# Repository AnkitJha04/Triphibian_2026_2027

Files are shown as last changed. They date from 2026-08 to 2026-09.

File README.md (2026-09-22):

# BE Capstone Project

## Project Title

RiftWalker: The Triphibious Bot

---

## Team Details

| Sr. No. | Name of Student | Roll No. | Branch | Email ID |
|---|---|---|---|---|
| 1 | Ankit Jha | 41 | Automation and Robotics  | 2023.ankitkumar.jha@ves.ac.in |
| 1 | Nidhi Kulkarni  | 15 | Automation and Robotics  | 2023.nidhi.kulkarni@ves.ac.in |
| 1 | Yadnyee Joshi | 10 | Automation and Robotics  | 2023.yadnyee.joshi@ves.ac.in  |
| 1 | Dnyanam Gala | 36 | Automation and Robotics  | 2023.dnyanam.gala@ves.ac.in |

---

## Guide Details

**Project Guide: Mrs. Sangeeta Prasanna Ram**  
**Department:** Automation and Robotics  
**Institute:** VESIT, Mumbai  

---

## Problem Statement

The objective of this project is to create an innovative, small unmanned robotic system that can function in air, land, and water domains through a unified propulsion and control mechanism and thus eliminates the requirement of using different systems such as UAV, UGV, and surface water vehicles in multi-environment missions.

Traditional unmanned systems are usually designed to work in one environment only. While the UAV offers high-speed flying abilities, it lacks endurance; the land robot offers efficiency but is limited by terrain; and the surface vehicle is incapable of crossing land barriers.

Recent studies have shown that integration of these two technologies is possible; however, triphibious robots are far fewer in number compared to dual-environment robots since integration leads to more weight and complexity in design and control, in addition to increased energy consumption.

---

## Abstract

Unmanned robotic systems are being increasingly employed for surveillance purposes, inspection tasks, emergency rescue operations and monitoring of the environment. But since most of these platforms are designed for one environment only, which could be air, land or water, missions in complex environments would either necessitate the use of multiple vehicles or halt the mission as the platform encounters the environment it cannot negotiate. It has been shown through studies on multimodal robots that multimodality is useful in increasing accessibility but it brings with it some difficulties in terms of weight, efficiency, mechanics and control.

The Riftwalker is a prototype of a triphibious robotic platform that aims to study movement in air, land and surface water using the same vehicle architecture. The platform uses four brushless motors as the source of propulsion in aerial environment while servo motors are used to orient the motors for different modes of operation. Passive wheels help the robot move on the ground while elements providing buoyancy help the robot operate in surface water environment.

The current design target has an approximately 2.2 kg maximum take-off mass, with calculated/design-stage performance targets of approximately 58 km/h aerial speed, 78 km/h peak ground speed and 10 km/h surface-water speed. These values will be treated as design targets until experimentally validated.

The expected outcome is a functional prototype demonstrating controlled movement and transition between three operating domains for applications including search and rescue, environmental surveying, inspection and remote reconnaissance.

Youtube video link :- https://youtu.be/WmMp18_r6lU

---

## Objectives

1. To study existing **multimodal and triphibious robotic platforms** and identify the challenges associated with integrating aerial, terrestrial and surface-water mobility into a single robotic system.

2. To develop a **3D CAD model** of the RiftWalker incorporating the structural frame, BLDC motor assemblies, servo-based tilting mechanism, wheels, buoyancy elements and electronics enclosure.

3. To design a **servo-based thrust vectoring mechanism** that changes the orientation of the BLDC propulsion units to enable different modes of locomotion using a unified propulsion system.

4. To perform **engineering calculations and feasibility analysis** including component-wise weight estimation, thrust-to-weight ratio, servo torque, battery and power requirements, land mobility, and water buoyancy.

5. To develop a custom **ESP32-S3 based flight controller PCB** integrating power management, motor and servo interfaces, USB-C programming, battery voltage monitoring and required sensor interfaces.

6. To integrate onboard sensors including the **MPU6050 IMU, magnetometer, barometer, ultrasonic sensor and water sensor** for orientation, altitude, obstacle and environmental-state monitoring.

7. To validate the proposed mechanical and electronic design through **simulation, PCB ERC/DRC verification and prototype testing**, ensuring that the system meets the defined design requirements.

8. To fabricate and integrate the mechanical, electronic and control subsystems and evaluate the **air, land and surface-water operating modes** of the RiftWalker prototype.

9. To document the complete design process, calculations, implementation, testing and results, and identify **future improvements and applications** of the proposed multi-terrain robotic platform.

---

## Scope of the Project

This project will cover the following key areas:

1) **3D mechanical design** and development of the servo-based thrust vectoring mechanism.
2) Selection and integration of **BLDC motors, ESCs, servos, wheels and buoyancy elements**.
3) Design of a custom **ESP32-S3 based flight controller PCB** with sensor, motor and servo interfaces.
4) Integration of sensors including **MPU6050, magnetometer, barometer, ultrasonic and water sensors**.
5) **Engineering calculations and simulation** for weight, thrust, torque, power and buoyancy.
6) Prototype fabrication, hardware integration and **testing of air, land and water operation**.
7) Performance evaluation and documentation of the developed system.

---

## Existing System

Existing unmanned robotic systems are generally designed for operation in a specific environment. They can broadly be classified as follows:

| Platform | Strength | Main Limitation |
|--- |--- |--- |
| UAV | Fast aerial movement and access to difficult locations | High energy consumption and limited endurance |
| UGV | Efficient and stable terrestrial operation | Restricted by water, steep terrain and other obstacles |
| USV | Efficient operation on surface water | Limited terrestrial mobility |
| Dual-Mode Robot | Capable of operating in two environments | Cannot independently access the third environment |
| Triphibious Robot | Potential to operate in air, land and water | Higher mass, mechanical complexity and control requirements |

Research has demonstrated the feasibility of combining multiple modes of locomotion within a single robotic platform. Existing triphibious and multimodal systems have explored approaches such as shared propulsion systems, tilting or morphing mechanisms and integrated mobility structures.

However, combining three different modes of locomotion introduces several engineering challenges, particularly in terms of **weight, energy efficiency, mechanical complexity, controllability and endurance**.

# Limitations of Existing Systems

1. **Multiple System Requirement:** Using separate UAV, UGV and waterborne platforms increases equipment, transportation and operational complexity.

2. **Limited Endurance:** Aerial systems require continuous thrust to remain airborne, resulting in significant power consumption.

3. **Terrain Limitations:** Ground robots may be restricted by water or difficult terrain, while waterborne platforms cannot easily overcome land-based obstacles.

4. **Increased Mechanical Complexity:** Combining separate propulsion and mobility mechanisms for different environments can increase the overall weight, power requirements and mechanical complexity of the system.

These limitations motivate the development of **RiftWalker**, which investigates the feasibility of combining aerial, terrestrial and surface-water mobility within a single robotic platform while sharing major propulsion, power and control components.

---

## Proposed System

RiftWalker proposes one reconfigurable vehicle rather than three independent vehicles.

Main Idea
The same central platform carries the battery, controller, communication system, sensors and propulsion hardware through all operating modes. Components are reused wherever practical rather than adding an independent propulsion system for every environment.

Operating Principle :
Air Mode
Four A2212-class 1400 KV BLDC motors with 9050 propellers operate in a multicopter configuration. The present design calculations indicate approximately 4.72 kg combined maximum static thrust against a 2.20 kg MTOW, corresponding to a calculated thrust-to-weight ratio of approximately 2.15:1.

Land Mode
The vehicle lands onto its wheel system. Servo-controlled propulsion orientation redirects available thrust to generate terrestrial motion rather than requiring a completely separate high-power traction architecture.

Water Mode
Buoyant wheel/body elements keep the electronics and major structure above the waterline while redirected propulsion produces forward motion across the water surface.

Control System : 
An ESP32-S3-class controller is currently proposed for prototype-level control, handling functions such as:
1) Stabilization/PID control,
2) IMU and navigation sensor processing,
3) Propulsion commands,
4) Servo actuation,
5) Mode management,
6) Telemetry,
7) Waypoint navigation.

Expected Benefits :

The expected benefit is mobility flexibility rather than superior performance in every individual domain.

A purpose-built UAV will likely fly more efficiently, a dedicated UGV can achieve better terrestrial endurance, and a purpose-built USV will generally perform better on water. RiftWalker instead investigates whether somewhat reduced domain-specific efficiency can be accepted in exchange for one platform being able to continue a mission when the terrain changes.
That is a much stronger and more realistic technical proposition.

---

## System Architecture

                    ┌─────────────────────┐
                    │   HUMAN OPERATOR    │
                    │ Ground Control / UI │
                    └──────────┬──────────┘
                               │
                     Telemetry / Commands
                               │
                               ▼
                  ┌────────────────────────┐
                  │ ONBOARD CONTROL SYSTEM │
                  │      ESP32-S3          │
                  │                        │
                  │ • Mission Logic        │
                  │ • PID / Stabilization  │
                  │ • Sensor Fusion        │
                  │ • Mode Management      │
                  │ • Navigation           │
                  └───────┬────────┬───────┘
                          │        │
                 ┌────────┘        └───────────┐
                 ▼                             ▼
        ┌─────────────────┐          ┌─────────────────┐
        │ SENSOR SYSTEM   │          │ ACTUATION       │
        │                 │          │ SYSTEM          │
        │ IMU             │          │                 │
        │ GNSS / NavIC    │          │ 4 × ESC         │
        │ Altitude        │          │ 4 × BLDC        │
        │ Camera*         │          │ Vector Servos   │
        └─────────────────┘          └────────┬────────┘
                                             │
                         ┌───────────────────┼──────────────────┐
                         ▼                   ▼                  ▼
                    AIR MODE            LAND MODE          WATER MODE
                    Multirotor          Wheels +           Buoyancy +
                    Flight              Vector Thrust      Vector Thrust
                         │                   │                  │
                         └───────────────────┼──────────────────┘
                                             ▼
                                  MULTI-DOMAIN MOBILITY

                     ┌─────────────────────────────┐
                     │       POWER SYSTEM          │
                     │  4S 6200 mAh LiPo Battery   │
                     │  Power Distribution / BEC   │
                     └─────────────────────────────┘

## System Architecture

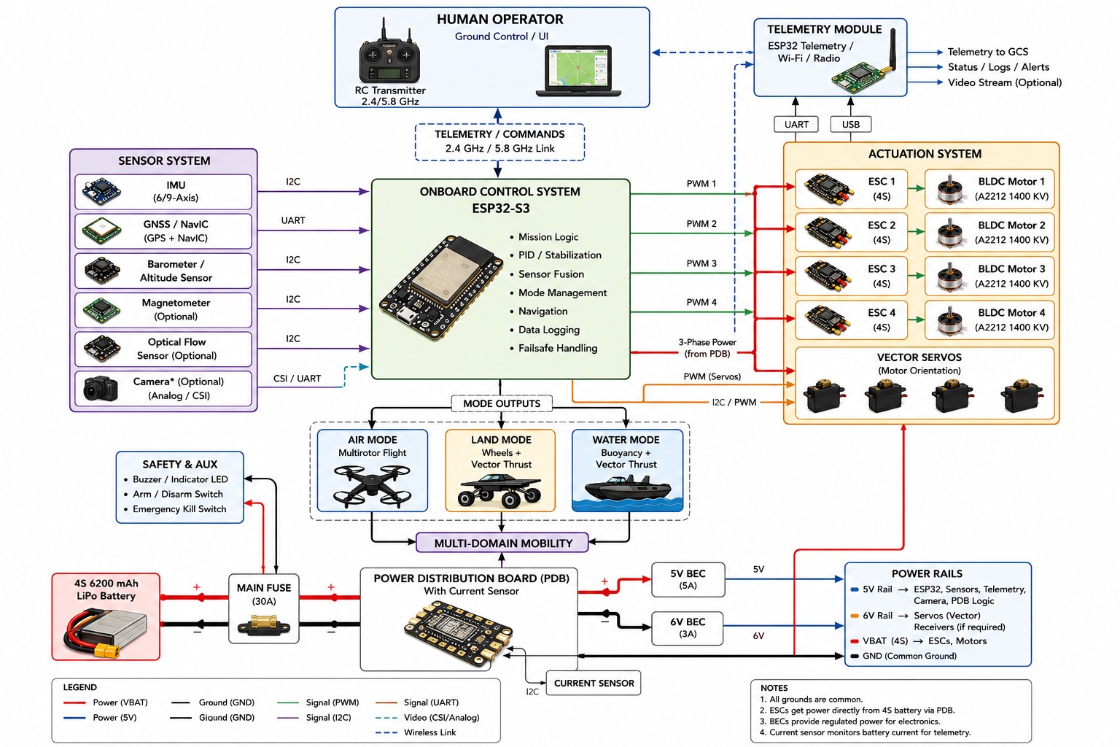
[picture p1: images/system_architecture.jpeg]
RiftWalker System Architecture


The RiftWalker system architecture is divided into four main sections:

Control System: The onboard controller acts as the brain of the robot. It processes sensor data, manages stabilization and navigation, controls propulsion, and switches between air, land, and water modes.
Sensor & Navigation System: Sensors such as the IMU and GNSS/NavIC provide information about orientation, position, motion, and vehicle state. Additional cameras or perception sensors can be integrated for autonomous navigation.
Propulsion & Actuation System: Four BLDC motors with ESCs generate thrust. Servo mechanisms change the direction of the propulsion system depending on the operating mode—vertical thrust for flight and redirected thrust for movement on land or water.
Power & Communication System: A 4S 6200 mAh LiPo battery supplies the motors, servos, controller, and sensors. A wireless telemetry link allows the ground operator to send commands and receive vehicle data.

Overall, the architecture is designed around sharing the same propulsion, power, sensing, and control hardware across all three environments, reducing the need for separate systems for each mode.

---

## Hardware Requirements

| Sr. No. | Component | Specification | Quantity | Purpose |
| --- | --- | --- | --- | --- |
| 1 | BLDC Motor | A2212, 1400 KV | 4 | Common propulsion for air, land and water |
| 2 | Propeller | 9050, matched to motor | 4 | Generates aerodynamic thrust |
| 3 | ESC | 4S-compatible, appropriately rated | 4 | Controls BLDC motor speed |
| 4 | LiPo Battery | 4S, 6200 mAh | 1 | Main onboard power source |
| 5 | Microcontroller | ESP32-S3 | 1 | Main control, sensor processing and telemetry |
| 6 | IMU | 6/9-axis accelerometer + gyroscope | 1 | Orientation, motion and stabilization |
| 7 | Sensor (Water/Distance) | Relevent to the use case | 1 | Outdoor positioning and navigation |
| 8 | Servo Motors | High-torque, metal-gear | 4 | Changes propulsion orientation between modes |
| 9 | Wheels | Lightweight passive/free-rolling | 4 | Supports terrestrial locomotion |
| 10 | Buoyancy System | Lightweight waterproof floats/body | 1 set | Provides stability and flotation on water |
| 11 | Power Distribution/BEC  | 4S compatible | 1 | Distributes and regulates electrical power |
| 12 | Telemetry System | Wireless bidirectional link | 1 | Operator commands and vehicle telemetry |
| 13 | Camera | Lightweight onboard camera | 1 | Visual feedback/perception |
| 14 | Frame & Mounting System | Lightweight rigid structure | 1 | Supports all mechanical and electronic components |
| 15 | Flight Controller | Custom | 1 | For functioning of everything perfectly |
---

## Software Requirements

| Sr. No. | Software / Tool | Version | Purpose |
| --- | --- | --- | --- |
| 1 | Arduino IDE / PlatformIO | Current stable | ESP32-S3 firmware development |
| 2 | Embedded C/C++ | Current toolchain | Low-level control and sensor interfacing |
| 3 | Python | 3.x | Data analysis, testing and algorithm prototyping |
| 4 | MATLAB / Simulink | Available release | Modelling, PID tuning and system analysis |
| 5 | Inventor | Available release | Mechanical CAD and assembly design |
| 6 | KiCad | Current stable | PCB and electronic system design |
| 7 | Git / GitHub | Current stable | Version control and project documentation |
| 8 | SimScale / OpenFOAM | Current stable | Computational Fluid Dynamics (CFD) simulation |
| 9 | Wokwi | Current stable | Headless hardware testing prior to flashing. |

---

## Technologies Used

1. **Embedded Systems:** ESP32-S3 and Embedded C/C++ for vehicle control and sensor interfacing.
2. **Sensor Integration & Control:** Integration of IMU, magnetometer, barometer, ultrasonic and water sensors for vehicle-state monitoring and control.
3. **PID Control:** PID-based stabilization and control of the propulsion system and vehicle motion.
4. **PCB Design (EDA):** KiCad for schematic design, component selection, PCB layout, routing and ERC/DRC verification.
5. **CAD & Mechanical Design:** Autodesk Inventor for 3D modelling, assembly design and development of the mechanical structure.
6. **Thrust Vectoring:** Servo-controlled motor orientation for redirecting propulsion across different operating modes.
7. **Multirotor Propulsion:** BLDC motors, ESCs and propellers for aerial propulsion.
8. **Power Management:** Separate logic and servo power domains with battery voltage monitoring and regulated power supplies.
9. **Wireless Communication:** Wireless communication for vehicle control and telemetry.
10. **Simulation & Engineering Analysis:** Mechanical and system-level analysis along with calculations for weight, thrust-to-weight ratio, servo torque, power requirements and buoyancy.

---

## Methodology

1. **Literature Survey:** Study existing multimodal and triphibious robotic platforms to understand their propulsion mechanisms, mobility approaches, control strategies and limitations.
2. **Problem Identification and Requirement Analysis:** Identify the major challenges involved in combining air, land and water mobility and establish the mechanical, electrical and performance requirements of RiftWalker.
3. **Concept Development:** Evaluate different multi-terrain mechanisms and finalize the use of a unified BLDC propulsion system with a **servo-based thrust vectoring mechanism**.
4. **Mechanical Design:** Develop the **3D CAD model in Fusion 360**, including the structural frame, motor mounts, servo tilting mechanism, wheels, buoyancy elements and electronics enclosure.
5. **Engineering Analysis:** Perform weight estimation, thrust-to-weight ratio, servo torque, battery and power, land mobility and buoyancy calculations to evaluate the feasibility of the proposed design.
6. **Simulation and Design Validation:** Validate the proposed mechanical concept and operating principle through simulation and analysis, and modify the design based on the obtained results.
7. **Electronic System Development:** Design the custom **ESP32-S3 based flight controller PCB** in KiCad, including power management, motor and servo interfaces, sensor interfaces, USB-C programming and battery monitoring.
8. **PCB Verification and Hardware Integration:** Perform schematic checks, ERC/DRC verification and PCB routing, followed by fabrication and integration of the controller with the motors, servos, sensors and power system.
9. **Firmware and Control Development:** Develop the ESP32-S3 firmware for sensor processing, stabilization, motor and servo control, communication and operating-mode management.
10. **Testing and Validation:** Test the integrated prototype in air, land and surface-water modes and evaluate parameters such as stability, mobility, thrust-vectoring response, power consumption and transition behaviour.
11. **Performance Analysis and Documentation:** Compare experimental results with calculated design values, identify limitations and improvements, and document the complete design, implementation and testing process.

---

## Project Timeline

| Week / Month | Task Planned | Status |
|---|---|---|
| **Week 1** | Problem Finalization & Project Planning | Completed |
| **Week 2** | Literature Survey & Research Paper Review | Completed |
| **Week 3** | Requirement Analysis & Component Selection | Completed |
| **Week 4** | Engineering Calculations | Completed |
| **Week 5** | Mechanical Design & 3D CAD Modelling | Completed |
| **Week 6** | Simulation & Design Validation | Completed |
| **Week 7** | Flight Controller PCB Design & Schematic Development | Completed |
| **Week 8** | PCB Routing, ERC/DRC Verification & Hardware Procurement | Completed |
| **Week 9** | PCB ic finalization & Component Weight testing | Completed |
| **Week 10**  | PCB Fabrication & Assembly | In Progress |
| **Week 11**  | Hardware Integration & Sensor Interfacing | In Progress |
| **Week 12**  | Firmware Development & System Testing | In Progress |
| **Week 13**  | Final Testing, Documentation & Project Demonstration | Pending |
| **Week 14**  | Research Paper Writing & Project Documentation | Pending |
| **Week 15**  | Final Presentation & Project Demonstration | Pending |

---

## Weekly Progress Updates

Students must update this section every week.
| Week  | Date | Work Completed | Next Week | Issues / Challenges | GitHub Commit |
|--- |--- |--- |--- |--- |--- |
| **1** | 22/06–28/06 | Problem finalization & planning | Literature survey | Concept feasibility | — |
| **2** | 29/06–05/07 | Literature survey & paper review | Requirement analysis | Mobility vs. weight | — |
| **3** | 06/07–12/07 | Requirements & components finalized | Engineering calculations | Weight, thrust & cost | — |
| **4** | 13/07–19/07 | Weight, thrust, torque & buoyancy calculations | Mechanical design | Maintaining low weight | — |
| **5** | 20/07–26/07 | 3D CAD model & mechanical design | Design validation & PCB | Mechanism integration | — |
| **6** | 27/07–02/08 | Design validation & simulation | PCB schematic | Mechanical-electronic integration | — |
| **7** | 03/08–09/08 | ESP32-S3 schematic & component selection | PCB routing & verification | GPIO & power management | — |
| **8** | 10/08–16/08 | PCB routing, ERC/DRC & documentation | PCB fabrication & procurement | Routing & component placement | — |
| **9** | 17/08–23/08 | Finalized and Completed PCB design verification| Working on software | Component availability | — |
| **10**| 24/08–30/08 | Made control center to control/code the drone  | PCB fabrication & procurement | Software needs and api development| — |

---

## Design Files

| File Type | File Name / Link | Description |
|-- |--- |--- |
| **CAD Model** | [Autodesk Inventor CAD Files](hardware/CAD/) | 3D mechanical model and assembly of RiftWalker |
| **Circuit Diagram** | [Circuit Diagram ](images/circuit_diagram-2.jpg) | Custom ESP32-S3 flight-controller schematic |
| **PCB Design** | [KiCad PCB Files](hardware/PCB/) | Custom flight-controller PCB design and routing |
| **ERC / DRC Reports** | [PCB Verification Files](hardware/PCB/) | Electrical and design rule verification reports |
| **Flowchart** | [System Flowchart](images/flowchart.jpeg) | Proposed operating sequence and control flow |
| **Simulation File** | [Wokwi Simulation Files](software/simulation/) | ESP32-based simulation files for preliminary testing | 

---

## Circuit Diagram

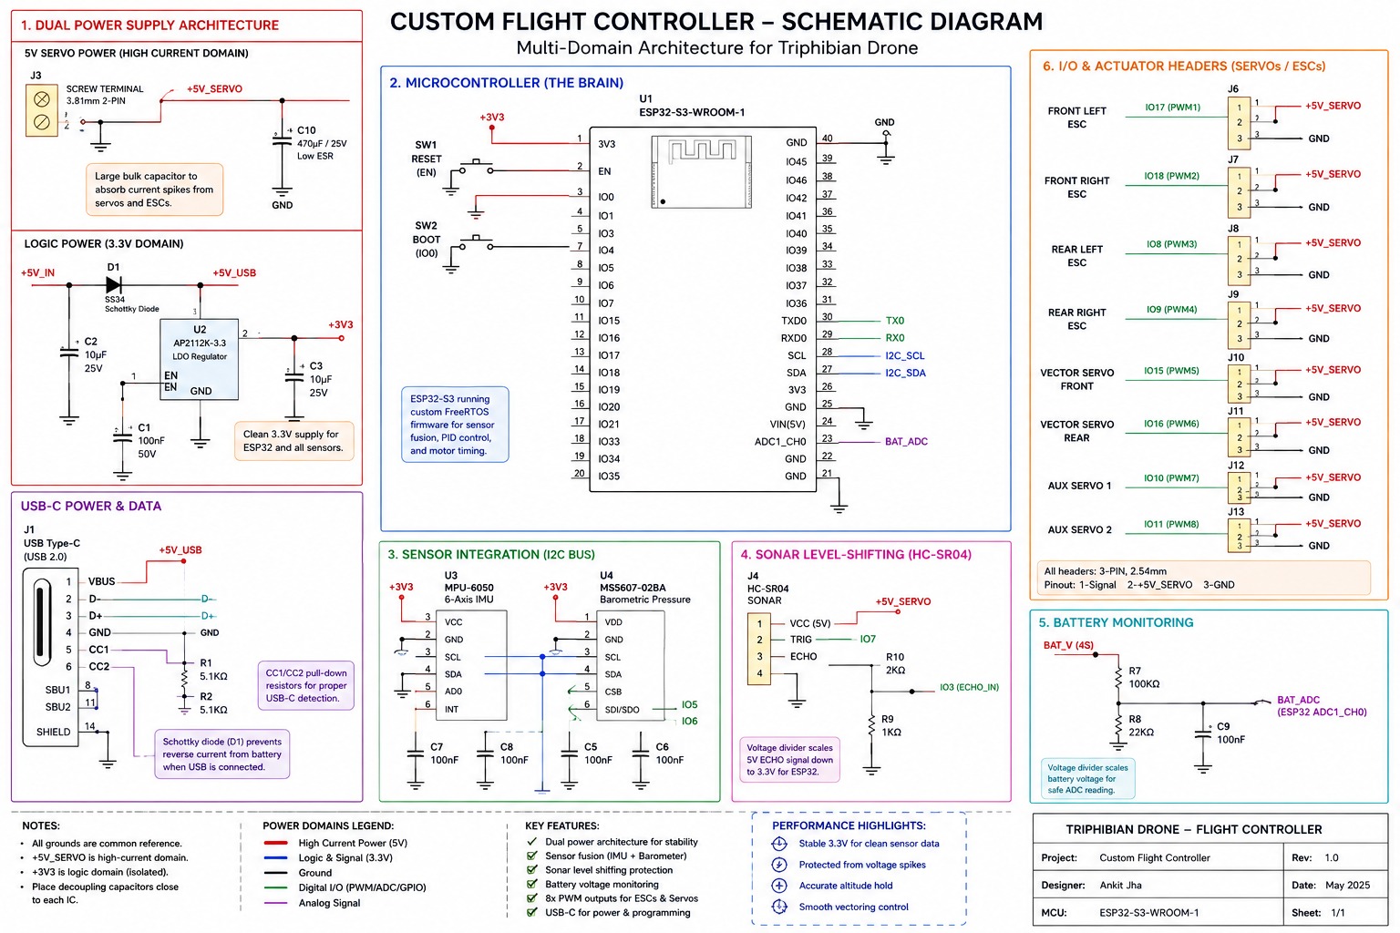
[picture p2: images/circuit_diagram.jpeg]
RiftWalker Circuit Diagram


---

## Flowchart / Algorithm

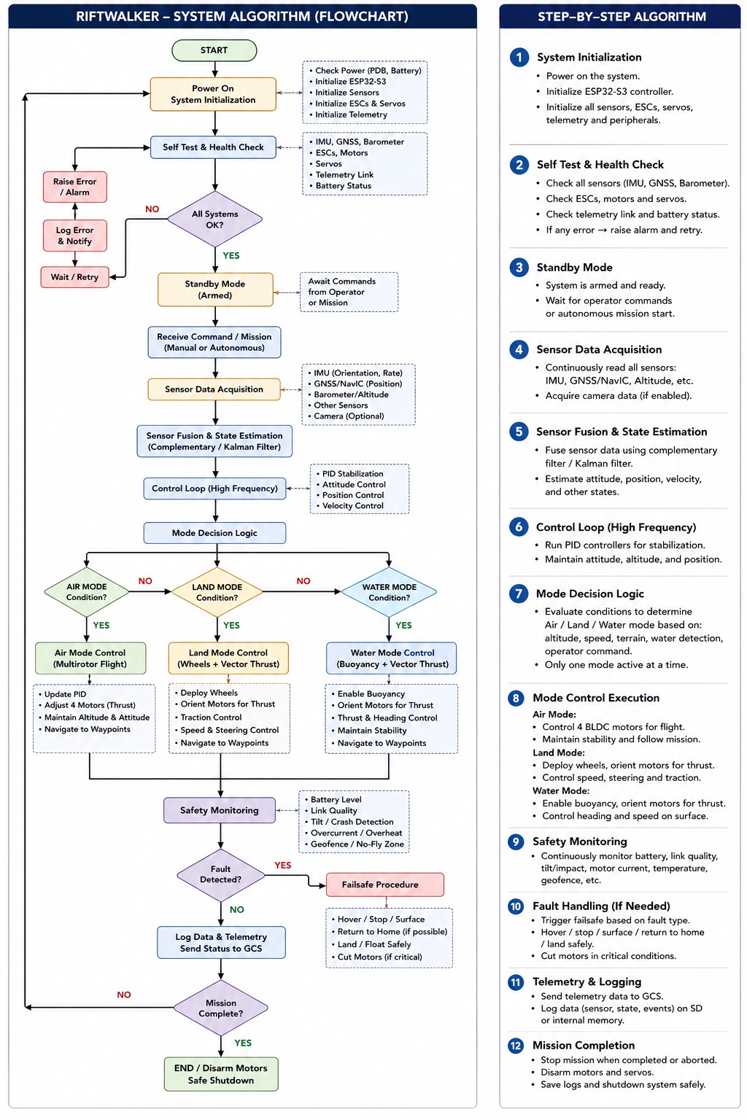
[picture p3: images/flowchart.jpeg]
RiftWalker Flowchart


### Algorithm

1. System Initialization – Power up the ESP32-S3 and initialize the IMU, GNSS/NavIC, altitude sensor, ESCs, servos and communication modules.
2. Self-Test & Health Check – Verify sensor communication, battery voltage, telemetry link and actuator status. Prevent arming if a critical fault is detected.
3. Standby / Arm – Keep propulsion disabled until a valid arm command and mission/operator command are received.
4. Sensor Acquisition – Continuously collect orientation, acceleration, altitude, position and other available sensor measurements.
5. Sensor Fusion & State Estimation – Combine measurements to estimate the robot's attitude, position, velocity and motion state.
6. Control Loop – Run the feedback controllers at high frequency to calculate the required thrust, attitude and motion corrections.
7. Mode Decision – Determine whether Air, Land or Water mode is requested/appropriate. For the prototype, operator-confirmed switching is safer than claiming fully autonomous terrain classification.
8. Execute Selected Mode – In Air Mode, operate as a multirotor; in Land Mode, redirect thrust and use the wheels; in Water Mode, maintain flotation and use vectored thrust for surface movement.
9. Navigation – Follow manual commands or mission waypoints while continuously updating the required heading, speed and position.
10. Safety Monitoring – Continuously check battery level, communication link, attitude, actuator/current limits and other available health information.
11. Failsafe Handling – If a critical fault occurs, execute the safest response available for the current mode, such as controlled landing, stopping propulsion, remaining afloat, or returning to a safe location where technically feasible.
12. Telemetry & Logging – Transmit vehicle status to the ground station and record important sensor, control and fault information.
13. Mission Check – If the mission is incomplete, return to the sensing/control loop. If complete, move to shutdown.
14. Safe Shutdown – Stop the mission, disarm propulsion and place actuators in their safe state.

---

## Implementation Details

The implementation of the RiftWalker project is divided into tightly integrated hardware and software phases, completely bypassing off-the-shelf drone kits in favor of a custom-engineered multi-domain architecture.

Hardware Implementation
Mechanical Frame & Buoyancy: The chassis utilizes custom Z-shaped carbon-fiber arms to elevate the propeller arcs, preventing aerodynamic thrust-blockage. Closed-cell XPS foam wheels are underslung on the chassis, providing mechanical ground clearance for land operations and acting as highly buoyant pontoons to keep the waterline below the main electronics bay during marine operations.

Actuation & Propulsion: The drive system relies on four BLDC motors mounted on rotating vectoring hubs. These hubs are actuated by high-torque DS3218 digital servos capable of sweeping the entire propulsion system 90 degrees forward for surface travel.

Custom Electronics (PCB): A custom-designed ESP32-S3 flight controller serves as the system's brain.

Power Distribution: The board features an isolated dual-power architecture. A high-current 5V rail (with a large bulk capacitor) drives the vectoring servos, while a dedicated AP2112K LDO regulator provides clean 3.3V power to the logic circuits, preventing brownouts.

Sensors: An MPU-6050 IMU and MS5607 barometer are mounted on the bottom layer of the PCB to shield them from thermal output and RF noise. An HC-SR04 ultrasonic sensor is integrated using a hardware voltage divider to safely step down the 5V echo pulse to the 3.3V logic level.

Software Implementation
Firmware Architecture: To handle the shape-shifting mechanics, the firmware was written entirely from scratch using C++ and FreeRTOS, bypassing the limitations of standard multirotor software.

Dual-Core Processing: The ESP32-S3’s dual-core capabilities are fully leveraged to ensure real-time stability:

Core 0 (Sensor Fusion): Dedicated exclusively to polling the IMU, barometer, and ultrasonic sensors. It calculates altitude and pressure to autonomously detect the operating domain (Air, Land, or Water).

Core 1 (Motor & PID Control): Strictly isolated to handle the high-speed PID stabilization loops and PWM timing for the ESCs and servos.

Concurrency & Safety: Hardware mutex locks are implemented to allow the two cores to share telemetry data safely. This guarantees that environmental sensor reads never delay the critical motor control loops, enabling instantaneous thrust-vectoring when transitioning between terrains.

## Code Structure

```text
BE-Capstone-Project/
│
├── README.md
│
├── docs/
│   └──  literature_survey.md
│
├── hardware/
│   ├── hardware.md
│   ├── pcb_design/
|       ├── DRC.rpt
|       ├── ERC.rpt
|       ├── Flight Controller.kicad_pcb
|       ├── Flight Controller.kicad_prl
|       ├── Flight Controller.kicad_pro
|       ├── Flight Controller.kicad_sch
|       ├── PCB Dimensions.png
|       ├── IC bom.xlsx
|       ├── README.md
|       └── fp-info-cache
│   ├── Tests/
|       ├── MotorAllSync.in
│   └── cad_model
|       ├── BLDC Holder.ipt
|       ├── BLDC Holder.stl
|       ├── Bearing.ipt
|       ├── Bearing.stl
|       ├── Body.ipt
|       ├── Body.stl
|       ├── Connecting Rod.ipt
|       ├── Connecting Rod.stl
|       ├── Final Body.iam
|       ├── Holder Cover.ipt
|       ├── Holder Cover.stl
|       ├── Motor.ipt
|       ├── Propeller.ipt
|       ├── README.md
|       ├── Servo.ipt
|       ├── Pcb Spacer.stl
|       ├── TEST ASSEMBLY 1.stl
|       ├── Top Cover.ipt
|       ├── Top Cover.stl
|       ├── Tyres.stl
|       └── Tyres.ipt
│
├── software/
│   ├── software.md
│   └── simulation/
|       ├── README.md
|       ├── diagram.json
|       ├── libraries.txt
|       ├── sketch.ino
|       └── wokwi-project.txt
|   └── Command and Control center/
|       ├── README.md
|       ├── index.html
|       ├── Commands.md
|       └── Application/
|           ├── README.md
|           ├── index.html
|           ├── app.py
|           ├── requirements.txt
│
├── images/
|   ├── circuit_diagram-2.jpg
|   ├── circuit_diagram.jpeg
|   ├── flowchart.jpeg
|   ├── images.md
|   └── system_architecture.jpeg
│
└── references/
    └── paper.md
```

---

## How to Run the Project

### Step 1: Clone the Repository

```bash
git clone https://github.com/username/project-name.git
```

### Step 2: Install Dependencies

```bash
pip install -r requirements.txt
```

or mention specific software/library installation steps.

### Step 3: Upload / Run the Code

```bash
python main.py
```

or

```bash
arduino-cli upload -p COMx --fqbn board_name
```

### Step 4: Observe the Output

When powered, the RiftWalker initializes its IMU and establishes a secure ESP-NOW link with the ground station, displaying battery voltage and current vector angles. Upon command, the craft can spool its motors to take off vertically like a standard drone, demonstrating stable hover capabilities. When the operator engages "Surface Mode," the servos smoothly rotate the motor arms $90^\circ$ forward while adjusting thrust to prevent altitude loss. On the ground or water, the vehicle utilizes differential aero-thrust to steer and propel itself forward at high speeds, gliding on its XPS wheels with a drastically reduced current draw compared to hovering.

---

## Testing and Results

| Test No. | Test Description | Expected Result | Actual Result | Status |
| --- | --- | --- | --- | --- |
| 1 | | | | Pass / Fail |
| 2 | | | | Pass / Fail |
| 3 | | | | Pass / Fail |

---

## Result Images / Videos

Add images or videos of the working prototype.

```markdown
![Prototype](images/prototype_photo.jpg)
```

Video Link:

```markdown
[Project Demo Video](https://drive.google.com/your-video-link)
```

---

## Applications

1. Post-Disaster Search & Rescue (SAR): Navigating through flooded urban environments, blocked roads, and debris dams where neither standard boats nor ground rovers can pass.
2. Hazardous Environmental Monitoring: Surveying toxic lakes, unstable wetlands, or swamp ecosystems without the risk of underwater propellers getting tangled in aquatic vegetation.
3. Tactical Reconnaissance & Border Patrol: Serving as a covert, multi-terrain sentinel capable of flying to a location rapidly and transitioning to a low-power, silent ground/water crawl for long-term observation.
4. Amphibious Ship-to-Shore Scouting: Launching from a naval vessel, flying to the coastline, and seamlessly driving onto the beach to conduct physical surveys.
ETC.

---

## Advantages

1. Elimination of Drivetrain Bloat: Achieves an exceptional 2.15:1 thrust-to-weight ratio by using a single set of aero-propellers for all terrains, eliminating the dead-weight of separate wheel motors and heavy gearboxes.
2. Exponential Endurance Gains: By dropping to the ground or water and operating as an aero-propelled rover, mission endurance is extended from a maximum of ~9.5 minutes in the air up to ~54.5 minutes on the surface.
3. Passive Buoyancy & Suspension: The lightweight XPS foam wheels serve a dual purpose, acting as excellent shock absorbers for rough terrain and fail-safe, unsinkable flotation hulls for water traversal.
4. Cost-Effective & Scalable: By eliminating redundant drive hardware and integrating a custom ESP32-based flight controller, the unit cost is drastically reduced compared to commercial military-grade amphibious systems.

---

## Limitations

1. Transition Vulnerability: The physical transition phase takes  seconds, during which the craft is highly susceptible to sudden crosswinds or aerodynamic stalling if not perfectly timed.
2. Ground Clearance Ceilings: Terrestrial obstacle clearance is strictly limited by the radius of the XPS wheels; the vehicle cannot drive over boulders or deep trenches without reverting to flight mode.
3. Acoustic Signature: Using aero-propulsion to drive on land generates significantly more noise (propeller wash) than a traditional electric wheeled rover, reducing its stealth capabilities in close-proximity scenarios.
4. Thermal Constraints: When planing on water at high throttle for extended periods, the enclosed central electronics box lacks active airflow cooling, potentially leading to thermal throttling of the ESCs.
   
---

## Future Scope

1. Autonomous AI Integration: Upgrading the processing core to incorporate a lightweight AI vision module (e.g., using the ESP32-S3's vector instructions or an external neural accelerator) for autonomous optical obstacle avoidance.
2. Triple-Redundant Aerospace Sensing: Developing a "V2" PCB that utilizes triple-redundant IMUs and Barometers connected via an SPI bus to create a fault-tolerant voting architecture for military-grade reliability.
3. BVLOS Telemetry Upgrade: Replacing the 2.4GHz ESP-NOW link with a secure, AES-encrypted Long Range (LoRa) 915MHz telemetry module for Beyond Visual Line of Sight (BVLOS) operations.
4. Aquatic Self-Righting Mechanism: Engineering an automated algorithmic response or physical mass-shifting mechanism to ensure the craft can self-right and recover if flipped upside down by heavy waves in water mode.
   
---

## Research Paper / Publication

| Item | Details |
| --- | --- |
| Paper Title | |
| Conference / Journal Name | |
| Paper Status | Not Started / Drafting / Submitted / Accepted / Published |
| Submission Date | |
| Paper Link | |

---

## References

[1] G. Zhong, J. Cao, X. Chai, and Y. Bai, "Design and Performance Analysis of a Triphibious Robot with Tilting-Rotor Structure," *IEEE Access*, vol. 9, pp. 10871–10879, 2021, doi: 10.1109/ACCESS.2021.3050182.

[2] X. Li, M. Lai, M. Zhang, J. Lin, T. Lai, J. Zhi, C. Xu, F. Gao, Y. Cao, "TriphiBot: A Triphibious Robot Combining FOC-based Propulsion with Eccentric Design," arXiv preprint arXiv:2602.01385, 2026.

[3] M. Xia, B. Wang, and Z. Luo, "Design and Experiment of a Multimodal Aerial Aquatic Vehicle with Morphing Wing and Tilting Rotors," *Advances in Mechanical Engineering*, vol. 17, 2025, doi: 10.1177/16878132251319142.

[4] S. L. Pradeep Kumar, B. Deeban, D. Santhosh Kumar, and M. Sasi Kumar, "Design and Fabrication of a Multi-Terrain Triphibian Quadcopter for Airborne, Terrestrial, and Aquatic Mobility," *Discover Mechanical Engineering*, vol. 5, art. no. 20, 2026, doi: 10.1007/s44245-025-00167-7.

[5] Z. Zheng, Q. Cai, J. Wang, X. Xu, M. Cao, H. Yu, J. Li, J. Meng, and G. Lu, "CapsuleBot: A Novel Hybrid Aerial-Ground Bi-Copter Robot With Two Actuated-Wheel-Rotors," *IEEE Robotics and Automation Letters*, vol. 10, no. 1, pp. 120–127, 2025, doi: 10.1109/LRA.2024.3504232.

---

## Repository Update Guidelines

Each student team must update the GitHub repository regularly.

Minimum expected updates:

* Update README every week.
* Push code changes regularly.
* Upload circuit diagrams, CAD files, PCB files, reports and presentations.
* Add weekly progress in the progress table.
* Maintain proper folder structure.
* Do not upload unnecessary temporary files.
* Each major update should have a meaningful commit message.

Example commit messages:

```text
Added problem statement and objectives
Updated system architecture diagram
Added sensor interfacing code
Updated weekly progress for Week 3
Added testing results and prototype images
```

---

## Declaration

We declare that this project work is carried out by our team as part of the BE Capstone Project. The work will be regularly updated on GitHub and all references used will be properly cited.

---

## License

This project is for academic use only.

Optional:

```text
MIT License / Creative Commons / Institute Use Only
```

```
```

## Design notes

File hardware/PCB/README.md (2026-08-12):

# RiftWalker PCB Design

This folder contains the KiCad schematic, PCB layout and verification files for the custom ESP32-S3 flight controller.

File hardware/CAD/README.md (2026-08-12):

# RiftWalker CAD Files

This folder contains the Autodesk Inventor 3D model and mechanical design files of RiftWalker.

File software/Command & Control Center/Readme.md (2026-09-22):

# RIFTWALKER / TRIPHIBIOUS COMMAND DECK — FINAL

Canonical interface file: **`Index.html`**

Desktop app: **`Application/app.py`** (loads that HTML). See the root `README.md` for run commands.

## What this build is based on
This build was rebuilt from the supplied project material rather than from the earlier generic dashboard alone:

- `Project Overview.md` — primary project architecture and operating principle.
- `Algorithm.png` — system initialization, health check, standby, sensor acquisition, fusion, control loop, mode decision, safety monitoring, failsafe and mission-completion flow.
- `Circuit Diagram Schematic Accurate.png` — custom flight-controller architecture and component/power/signal relationships.
- `Circuit Diagram.png` and `System Architecture.png` — system-level arrangement and multi-domain actuation/sensing relationships.
- `Major Project Simulation.zip` — Wokwi/ESP32 prototype firmware and wiring. This is treated as a prototype reference, not silently substituted for the final PCB.
- `Related Defence Projects.pdf` — supplied application/use-case material.
- Previous RiftWalker HTML files — used for visual/tactical presentation language only, not as the technical authority.

## Important source reconciliation
The project overview describes the final propulsion architecture as four A2212 BLDC motors, four ESCs and four 1045 propellers with four servo-driven motor pivots. The supplied Wokwi simulation is a bench prototype using an ESP32 DevKit, MPU6050, BMP180, SSD1306, HC-SR04, four A4988 drivers/stepper motors and four servos. The dashboard deliberately keeps these two layers separate so a prototype component is not presented as a final hardware component.

## Included functionality

### 1. Digital twin
- Four propulsion pods and four vector pivots.
- A2212 + 1045 propulsion representation.
- Four foam wheels for land contact and water buoyancy.
- Air / Land / Water state-dependent animation.
- Animated propeller motion tied to throttle.
- Vector angle moves at 120 degrees/second in the local model, matching the documented prototype design intent.
- Camera presets and mouse orbit/zoom on the flight view.

### 2. Telemetry
Local simulation is always functional and deterministic. It reports:
- mode
- throttle
- speed
- altitude/distance
- pressure
- battery
- roll
- pitch
- current
- power
- individual vector-servo state (front/rear mirror values follow the uploaded prototype's `180-angle` / `angle` mapping)

The UI does **not** call local simulation telemetry “hardware telemetry”.

Environment pressure scales thrust, speed, and current once per simulation step. It does not compound every animation frame.

### 3. Real ESP32 link
The Ground Control tab uses this explicit contract:

- `GET /health`
- `GET /telemetry`
- `POST /command` with JSON

Example telemetry response:

```json
{
  "ok": true,
  "mode": "air",
  "throttle": 42,
  "vector": 90,
  "altitude": 1.25,
  "pressure": 998.4,
  "speed": 18.2,
  "roll": -1.1,
  "pitch": 2.4,
  "battery": 91,
  "current": 18.6,
  "power": 275
}
```

Example command response:

```json
{
  "ok": true,
  "applied": true,
  "command": "SET_THROTTLE"
}
```

The interface only displays `ACK`/`APPLIED` after the device actually answers. Network failure is shown as `FAIL`.

### 4. Hardware / PCB
The interactive PCB map follows the supplied custom schematic's logical placement:
- ESP32-S3 central controller
- MPU6050 / magnetometer sensor area
- AP2112K 3.3 V regulation area
- ESC outputs
- vector-servo outputs
- propulsion/wheel blocks
- USB-C service
- battery ADC
- prototype sonar/water sensing

The exact supplied schematic is also available inside the Hardware tab.

### 5. Use cases
The mission library is custom to the supplied triphibious architecture:
- Flood Rescue / Access
- Coastal Survey
- Hazardous Area Inspection
- Industrial / Dam Inspection
- Disaster Recon
- Wetland / Environment

Each scenario has its own environment sequence, route, phase list and animation rather than a generic route reused for every case.

## Prototype pin map retained from the uploaded Wokwi code
The uploaded prototype uses:

| Function | GPIO |
|---|---:|
| FWD / BCK | 26 / 25 |
| LEFT / RIGHT | 17 / 15 |
| WATER | 16 |
| Throttle ADC | 34 |
| Ultrasonic | TRIG 5 / ECHO 35 |
| Vector servos | 18 / 19 / 23 / 4 |
| Step outputs | 27 / 14 / 13 / 12 |
| DIR | 32 / 33 |
| I2C SDA / SCL | 21 / 22 |

The firmware also uses FreeRTOS tasks for motor and sensor processing.

## Why the previous telemetry problem is not hidden
The uploaded Wokwi sketch does not implement a Wi-Fi HTTP telemetry server. Therefore a browser cannot truthfully fetch live hardware telemetry directly from that exact sketch. This dashboard therefore:

1. runs a complete local simulation without pretending it is hardware;
2. provides the hardware API adapter separately;
3. requires the ESP32 firmware to expose `/health`, `/telemetry` and `/command` before it will show real device ACK/data.

This is intentional: a green “ESP32 LIVE” indicator is never produced merely because the UI changed a local variable.

## Run
**Browser:** open `Index.html`.

**Desktop:** `python Application/app.py` after `python -m pip install -r Application/requirements.txt`.

No CDN or framework is required for the simulation interface.

For hardware mode, the client must reach the ESP32 IP and the firmware must implement the API contract above. CORS must be allowed when the page is not served from the ESP32 origin.

## Recommended hardware-side next step
Add the API adapter to the actual ESP32-S3 firmware. Do not retrofit the Wokwi stepper/A4988 test architecture into the final PCB merely to make the dashboard appear to work. The final project documentation identifies A2212/ESC/1045 propulsion and servo-based motor orientation; the Wokwi file is the prototype test bench.

## Safety
This interface is a visualization/control-deck prototype. It must not be used as a safety-certified flight controller. Real motor/servo testing should be performed with propellers removed or in an appropriate restrained test setup and with an independent physical emergency-disarm path.

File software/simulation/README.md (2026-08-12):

# RiftWalker Wokwi Simulation

This folder contains the Wokwi-based simulation files used for preliminary testing of the ESP32 control system, sensors, servo outputs and motor-control interfaces.

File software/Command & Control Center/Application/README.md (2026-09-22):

# Riftwalker Triphibious Command Deck (desktop)

Native Python window for the Command Deck. It hosts the exact same interface as `TRIPHIBIOUS_Command_Deck_FINAL_FIXED.html` (copied here as `index.html`).

## Requirements

- Windows 10/11
- Python 3.10 or newer
- Packages in `requirements.txt` (PySide6 + Qt WebEngine via PySide6-Addons)

## Install and run

```powershell
cd Application
python -m pip install -r requirements.txt
python app.py
```

From the project root:

```powershell
python -m pip install -r Application\requirements.txt
python Application\app.py
```

On Windows you can also double-click `run.bat` in this folder. If Python packages are missing, that script installs `requirements.txt` and starts the app.

If Qt WebEngine is missing:

```powershell
python -m pip install --upgrade PySide6 PySide6-Addons PySide6-Essentials
```

## What it loads

`app.py` serves and displays, in this order if present:

1. `../TRIPHIBIOUS_Command_Deck_FINAL_FIXED.html`
2. `TRIPHIBIOUS_Command_Deck_FINAL_FIXED.html` in this folder
3. `index.html` in this folder

`index.html` is kept identical to the canonical HTML so this folder remains runnable by itself.

## Features (same as the HTML deck)

- Dark Riftwalker command-deck UI
- SYSTEM, DIGITAL TWIN, HARDWARE / PCB, USE CASES, GROUND CONTROL, REFERENCE GALLERY
- Digital twin with chassis, battery bay, four motor pods, vector pivots, propellers, tyres, and foam floats
- Drag to orbit, wheel to zoom, ISO / TOP / FRONT / SIDE cameras
- Air / Land / Water modes; vector tilts propellers only
- Environment pressure and Ground Control UP / DOWN move the model inside the same canvas
- Throttle, vector, and environment pressure
- Local telemetry; ESP32 feed only after a real device ACK
- Local telemetry; ESP32 feed only after a real device ACK
- Scrollable reference gallery with the supplied project images

## Hardware adapter

Unchanged API:

- `GET /health`
- `GET /telemetry`
- `POST /command`

Default device URL in Ground Control: `http://192.168.4.1`

The desktop app remains fully usable in local simulation if no ESP32 is connected.

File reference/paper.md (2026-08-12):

# RiftWalker Academic Literature Foundation

**Overview:** This document outlines the primary academic literature that established the theoretical and mechanical foundation for the RiftWalker project. Each paper below played a specific, critical role in shaping our engineering decisions, from the unified propulsion architecture to the fluid-dynamic structural design.

---

### [1] Design and Performance Analysis of a Triphibious Robot with Tilting-Rotor Structure
* **Citation:** G. Zhong, J. Cao, X. Chai, and Y. Bai, "Design and Performance Analysis of a Triphibious Robot with Tilting-Rotor Structure," *IEEE Access*, vol. 9, pp. 10871–10879, 2021. 
* **DOI:** [10.1109/ACCESS.2021.3050182](https://doi.org)

#### How it influenced RiftWalker
This research validated tilt-rotor thrust vectoring across air, land, and water environments, directly inspiring our 90-degree servo-actuated motor tilt mechanism.
---

### [2] TriphiBot: A Triphibious Robot Combining FOC-based Propulsion with Eccentric Design
* **Citation:** X. Li, M. Lai, M. Zhang, J. Lin, T. Lai, J. Zhi, C. Xu, F. Gao, Y. Cao, "TriphiBot: A Triphibious Robot Combining FOC-based Propulsion with Eccentric Design," *arXiv preprint arXiv:2602.01385*, 2026.
* **Link:** [arXiv:2602.01385](https://arxiv.org)

#### How it influenced RiftWalker
This paper’s core thesis on unified propulsion architecture demonstrated unified cross-medium propulsion without extra actuators, confirming that reusing flight motors eliminates the parasitic mass of secondary drivetrains.
---

### [3] Design and Experiment of a Multimodal Aerial Aquatic Vehicle with Morphing Wing and Tilting Rotors
* **Citation:** M. Xia, B. Wang, and Z. Luo, "Design and Experiment of a Multimodal Aerial Aquatic Vehicle with Morphing Wing and Tilting Rotors," *Advances in Mechanical Engineering*, vol. 17, 2025.
* **DOI:** [10.1177/16878132251319142](https://doi.org)

#### How it influenced RiftWalker
This study evaluated structural and aerodynamic adaptations for cross-domain transitions, guiding our Z-shaped offset arm geometry to prevent propeller downwash from hitting the main chassis.

---

### [4] Design and Fabrication of a Multi-Terrain Triphibian Quadcopter for Airborne, Terrestrial, and Aquatic Mobility
* **Citation:** S. L. Pradeep Kumar, B. Deeban, D. Santhosh Kumar, and M. Sasi Kumar, "Design and Fabrication of a Multi-Terrain Triphibian Quadcopter for Airborne, Terrestrial, and Aquatic Mobility," *Discover Mechanical Engineering*, vol. 5, art. no. 20, 2026.
* **DOI:** [10.1007/s44245-025-00167-7](https://doi.org)

#### How it influenced RiftWalker
While other papers focused heavily on kinematics, this research provided a practical design and fabrication benchmark for multi-terrain quadcopters, shaping our modular chassis build and tactical real-world deployment cases.

---

### [5] CapsuleBot: A Novel Hybrid Aerial-Ground Bi-Copter Robot With Two Actuated-Wheel-Rotors
* **Citation:** Z. Zheng, Q. Cai, J. Wang, X. Xu, M. Cao, H. Yu, J. Li, J. Meng, and G. Lu, "CapsuleBot: A Novel Hybrid Aerial-Ground Bi-Copter Robot With Two Actuated-Wheel-Rotors," *IEEE Robotics and Automation Letters*, vol. 10, no. 1, pp. 120–127, 2025.
* **DOI:** [10.1109/LRA.2024.3504232](https://doi.org)

#### How it influenced RiftWalker
This paper demonstrated dual-use actuator sharing between aerial flight and ground rolling, inspiring our reliance on differential thrust and dual-purpose wheels over heavy steering racks.

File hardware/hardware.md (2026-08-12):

<div align="center">
  <h1 style="font-family: 'Helvetica Neue', Arial, sans-serif; font-weight: 300; letter-spacing: 3px; color: #1a202c; margin-bottom: 0;">
    HARDWARE ARCHITECTURE
  </h1>
  <p style="font-size: 1.3em; color: #3182ce; font-weight: bold; margin-top: 5px; letter-spacing: 1.5px;">
    RiftWalker: Unified Triphibious Robotics
  </p>
  <hr style="width: 120px; border: 2px solid #3182ce; border-radius: 2px; margin-top: 15px; margin-bottom: 35px;">
</div>

<blockquote>
  <strong>Welcome to the RiftWalker Hardware Repository.</strong> This document outlines the physical engineering and custom avionics required to build the RiftWalker platform. By completely abandoning off-the-shelf drone frames and standard flight controllers, this hardware is purpose-built to eliminate parasitic dead-weight and enable unrestricted multi-domain mobility across Air, Land, and Water.
</blockquote>

<br>

---

##  Repository Structure

```text
├── /CAD            # 3D models and structural files
    Required Cad Files
├── /PCB            # KiCad project files and Schematics
    Required PCB Files
```

<br>

---

## Mechanical Design (Frame & Actuation)

The physical chassis is explicitly engineered to solve two major triphibious challenges: aerodynamic blockage and terrain-locking.

*   **Z-Shaped Carbon-Fiber Arms:** The motor arms step upwards in a distinct Z-shape. This elevates the propeller arc, completely clearing the main chassis from the downward airflow, thereby preventing parasitic thrust-blockage.
*   **Dynamic Vectoring Hubs:** Instead of adding extra drivetrains, high-torque digital servos physically sweep the BLDC propulsion system **90 degrees forward**. This allows RiftWalker to steer using differential thrust on both the ground and water.
*   **Multi-Domain XPS Wheels:** The underslung wheels are constructed from closed-cell XPS foam. On land, they provide mechanical ground clearance; on water, they act as precisely calculated buoyant pontoons, forcing the waterline strictly below the electronics bay.

<br>

---

## Custom Avionics (ESP32-S3 PCB)

Off-the-shelf flight controllers are bloated and strictly designed for single-domain use. We engineered a custom **ESP32-S3-WROOM-1** PCB from scratch to gain total hardware access for our dual-core FreeRTOS architecture.

### Key PCB Design Decisions:

#### 1. Strict Power Isolation
*   **Logic (3.3V):** Powered by an AP2112K LDO regulator, providing clean, stable power to the ESP32 and $I^2C$ sensors.
*   **Actuators (5V):** Servo power is completely decoupled from the logic circuit. A large bulk polarized capacitor (`C10`) is placed on the 5V rail to absorb the massive current spikes caused by the vectoring servos, preventing mid-air brownouts.

#### 2. Sensor Thermal & RF Shielding
The **MPU-6050** (6-axis IMU) and **MS5607** (Barometer) are intentionally mounted on the **bottom layer** of the PCB. This physically isolates them from the ESP32’s thermal output and RF noise, ensuring perfectly clean environmental data.

#### 3. Antenna Keep-Out Zone
A strict copper keep-out zone is enforced around the ESP32 antenna to maximize telemetry and control range across all terrains.

#### 4. Safe Logic-Level Shifting
The HC-SR04 ultrasonic sensor outputs a 5V echo pulse. A precise $2\text{k}\Omega / 1\text{k}\Omega$ hardware voltage divider safely steps this down to 3.3V, protecting the microcontroller's GPIO pins.

<br>

---

## Bill of Materials (Core Components)

| Component | Description | Qty |
| :--- | :--- | :---: |
| **ESP32-S3-WROOM-1** | Dual-core MCU for custom FreeRTOS flight logic | 1 |
| **MPU-6050** | 6-Axis IMU (Pitch/Roll/Yaw stabilization) | 1 |
| **MS5607-02BA** | High-precision barometer for altitude detection | 1 |
| **HC-SR04** | Ultrasonic distance sensor | 1 |
| **BLDC Motors & ESCs** | Primary unified propulsion | 4 |
| **High-Torque Servos** | Actuates the 90-degree vectoring sweep | 4 |
| **AP2112K-3.3** | 3.3V Low-Dropout Voltage Regulator | 1 |

<br>

---
*For software implementation, firmware flashing instructions, and FreeRTOS details, please refer to `SOFTWARE.md`.*

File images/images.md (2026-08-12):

# RiftWalker Visual Repository

Welcome to the RiftWalker Visual Repository. This document serves as a visual index and explanation for the core engineering diagrams driving our platform. It breaks down the high-level mechatronic architecture, the custom electrical routing, and the dual-core software logic required for seamless triphibious operation.

---

## 1. System Architecture
*Reference: `system_architecture.jpeg`*

This diagram illustrates the top-down flow of commands and the physical unification of our hardware.

* **The Command Flow:** Human operator telemetry is received by the **ESP32-S3 Onboard Control System**. This central brain handles mission logic, PID stabilization, and sensor fusion.
* **The Hardware Split:** The controller pushes data to two distinct branches:
  * **Sensor System:** The IMU (Pitch/Roll), Barometer (Altitude), and Ultrasonic sensors.
  * **Actuation System:** The 4× BLDC flight motors and the high-torque vectoring servos.
* **The Triphibious Convergence:** Unlike traditional diagrams that show separate motors for different terrains, our architecture diagram shows a single actuation system converging into **Air Mode** (multirotor), **Land Mode** (wheels + vector thrust), and **Water Mode** (buoyancy + vector thrust). It visually proves our absolute elimination of parasitic dead-weight.

---

## 2. Circuit Diagram 
*Reference: `circuit_diagram.jpeg`*

The circuit diagrams map out our core strategy for isolating high-current electrical noise from sensitive flight logic.

* **Dual Power Routing (Schematic):** The schematic visually separates the **5V Actuator Bus** (driving the servos) from the **3.3V Logic Bus** (regulated by the AP2112K). A large bulk capacitor (`C10`) is placed directly on the servo power terminal to act as a physical buffer against voltage drops.
* **Safe Logic Shifting:** The schematic details the exact 2KΩ / 1KΩ resistor network used to safely step down the 5V ultrasonic echo pulse before it reaches the 3.3V GPIO pins of the ESP32.
* **Physical Board Layout (3D Render):** The PCB layout visually demonstrates our interference protection strategies. The IMU and Barometer are placed strictly on the **bottom layer** to shield them from the ESP32’s heat. Concurrently, the top layer features a massive, visually distinct **Copper Keep-Out Zone** around the antenna to ensure maximum RF range.

---

## 3. Software Flowchart (State Machine)
*Reference: `flowchart.jpeg*

This flowchart maps the real-time execution of our custom FreeRTOS firmware and outlines how the robot autonomously decides its physical shape.

* **Initialization & Core Split:** The program flow starts by dividing tasks. Core 0 handles the asynchronous `SensorTask` loop, while Core 1 handles the high-speed `MotorTask` loop. Hardware Mutex Locks are visualized as bridges allowing safe data transfer between the two processing loops.
* **Domain Detection Logic:**
  * **Decision Node 1 (Water):** If the water sensor triggers `LOW` ➔ Vector 0° ➔ **Water Mode** (Differential Thrust).
  * **Decision Node 2 (Air):** If Pressure < 1000 hPa AND Distance > 100cm ➔ Vector 90° ➔ **Air Mode** (PID Stabilization).
  * **Default State:** If neither condition is met ➔ Vector 0° ➔ **Land Mode** (Differential Thrust).
* **Execution Loop:** The flowchart maps how Core 1 continuously clamps RPM values and calculates strict microsecond step-delays based on the active domain state, proving that environmental checks never bottleneck the motor response pulses.

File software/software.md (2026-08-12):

# RiftWalker Software Repository

Off-the-shelf flight controllers (like Betaflight or ArduPilot) are strictly optimized for single-domain operation. To control a shape-shifting triphibian robot, the RiftWalker project bypasses pre-existing software entirely. This repository contains our custom C++ firmware, heavily utilizing FreeRTOS on the ESP32-S3 to achieve true, uninterrupted multi-domain mobility.

---

## Dual-Core RTOS Architecture

To guarantee absolute system stability, the firmware leverages the ESP32-S3’s dual-core processor. We strictly isolated environmental sensing operations from the high-speed motor control loops.

### Core 0: Sensor Fusion & Telemetry (`SensorTask`)
Core 0 is completely dedicated to reading environmental data and driving the OLED user interface.

* **Domain Detection:** The system continuously polls barometric pressure and ultrasonic distance. If the pressure drops below 1000 hPa and the distance exceeds 100 cm, the system autonomously registers its state as `AIR MODE`.
* **Dynamic Reconfiguration:** Upon detecting a terrain shift, Core 0 instantly commands four onboard servos to sweep 90 degrees. This action physically shape-shifts the robot from a driving/sailing configuration into a multirotor flight configuration.

### Core 1: Flight Control & Motor Timing (`MotorTask`)
Core 1 is isolated purely for high-speed mathematical corrections and Electronic Speed Controller (ESC) driving.

* **Forward-Only PID Stabilization:** When operating in Air Mode, this core runs a custom PID algorithm utilizing pitch and roll data from the IMU. To maintain aerodynamic stability without mechanical stuttering, the motor logic is clamped to strictly apply *forward* RPM corrections—the motors never reverse direction to compensate for tilt.
* **Differential Thrust Mapping:** In Land or Water mode, the standard PID loop is bypassed. Core 1 instead implements differential thrust mapping (push-pull mixing). This allows the system to steer the robot entirely by varying the left and right motor RPMs, eliminating the need for a mechanical steering rack.

---

## Concurrency & Safety (Mutex Locks)

Because Core 0 (Sensors) and Core 1 (Motors) operate asynchronously, data collisions could cause a catastrophic mid-air failure. To prevent this, the architecture implements **Hardware Mutex Locks** (`portENTER_CRITICAL` / `portEXIT_CRITICAL`). 

When Core 0 updates telemetry data (Pitch, Roll, and Altitude), it briefly locks the shared memory space. Core 1 reads this shared data securely and unlocks it within microseconds. This mechanism guarantees that any unexpected I2C sensor delay will *ever* interrupt critical motor timing pulses.

---

## Wokwi Simulation Environment

Before flashing the custom printed circuit board (PCB), the system logic was fully verified within a simulated environment using the following implementation strategies:

* **Actuator Simulation:** Because Wokwi does not natively support high-speed brushless DC (BLDC) ESCs, the flight motors are simulated using four A4988 stepper drivers. By calculating strict microsecond delays through a custom `pulse()` function, the simulation successfully mimics precise RPM control and thrust mixing.
* **UI Verification:** An SSD1306 OLED displays real-time system states (`SAILING`, `DRIVING`, `STABLE`), proving that dual-core memory sharing operates flawlessly under maximum processing load.

---

*For mechanical dimensions, PCB schematics, and component isolation strategies, please refer to [`HARDWARE.md`](HARDWARE.md).*

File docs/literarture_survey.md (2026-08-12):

<div align="center">
  <h1 style="font-family: 'Helvetica Neue', Arial, sans-serif; font-weight: 300; letter-spacing: 3px; color: #1a202c; margin-bottom: 0;">
    LITERATURE SURVEY
  </h1>
  <p style="font-size: 1.3em; color: #3182ce; font-weight: bold; margin-top: 5px; letter-spacing: 1.5px;">
    RiftWalker Triphibious Robotic Platform
  </p>
  <hr style="width: 120px; border: 2px solid #3182ce; border-radius: 2px; margin-top: 15px; margin-bottom: 35px;">
</div>

<blockquote>
  <strong>Overview:</strong> Recent advancements in autonomous systems have catalyzed the development of multi-domain robotic platforms capable of traversing land, air, and aquatic environments. Researchers are actively exploring unified propulsion architectures, dynamic mechanical reconfiguration, and advanced control logic to optimize cross-domain mobility. The following literature review analyzes the current state-of-the-art in triphibious systems, identifying critical mechanical strengths and structural limitations to establish the engineering foundation for the <strong>RiftWalker</strong> mechatronic architecture.
</blockquote>

<br>

---

## Reviewed Literature

### 1. Kinematic Reconfiguration via Tilting-Rotor Structures (2020)
*   **Paper:** *"Design and Performance Analysis of A Triphibious Robot with Tilting-Rotor Structure"*
*   **Core Mechanism:** This study investigates the application of a tilt-rotor mechanism to dynamically alter propeller thrust vectors, enabling seamless mechanical transitions between distinct modes of locomotion without requiring redundant drive systems.
*   **RiftWalker Inspiration:** This research successfully validated `dynamic thrust vectoring` as a mathematically and mechanically superior method for multi-terrain mobility. It serves as the direct foundational inspiration for RiftWalker's 90-degree, servo-actuated vectoring hubs, allowing us to actively shift the propulsion plane.

---

### 2. Actuator Multiplexing and Propulsive Unification (2026)
*   **Paper:** *"TriphiBot: A Triphibious Robot"*
*   **Core Mechanism:** The authors propose a highly unified propulsion architecture that completely eliminates secondary drivetrains. Instead of integrating independent mechanisms for flying, driving, and swimming, the system intelligently reuses a single set of motors across all three environmental domains.
*   **RiftWalker Inspiration:** This approach decisively solves the issue of `parasitic dead-weight`. By adopting this unified philosophy, RiftWalker uses the exact same BLDC flight motors to generate aerial lift and provide differential thrust for terrestrial and marine steering, drastically reducing overall system complexity and gross takeoff weight.

---

### 3. Aerodynamic Transitions in Multimodal Vehicles
*   **Paper:** *"Design and Experiment of a Multimodal Aerial-Aquatic Vehicle with Morphing Wing and Tilting Rotors"*
*   **Core Mechanism:** The paper introduces a reconfigurable morphing structure paired with tilting rotors, specifically optimized to handle the extreme fluid dynamic differences between aerial downwash and aquatic displacement.
*   **RiftWalker Inspiration:** The study confirmed that dynamically changing rotor geometry is critical for operational flexibility and efficiency. This heavily influenced our structural design—specifically our `Z-shaped carbon-fiber arms`—which elevate the propeller arc to ensure the chassis does not block downward airflow, locking in a high thrust-to-weight ratio.

---

### 4. Pragmatic Deployment of Multi-Terrain Quadcopters
*   **Paper:** *"Design and Fabrication of a Multi-Terrain Triphibian Quadcopter"*
*   **Core Focus:** This research shifts focus toward real-world deployment, evaluating multi-domain platforms in the context of precision agriculture, hazardous infrastructure inspection, and rapid disaster management.
*   **RiftWalker Inspiration:** The study explicitly highlighted how unifying three vehicular roles into a single platform drastically reduces operational overhead and boosts mission response times. This strategic analysis directly shaped the target use-cases for RiftWalker, emphasizing `terrain independence` for tactical and search-and-rescue operations.

---

### 5. Extreme Hardware Optimization (2023)
*   **Paper:** *"CapsuleBot: Hybrid Aerial-Ground Robot"*
*   **Core Mechanism:** This paper demonstrates a hybrid model that shares the exact same actuators for both airborne flight and terrestrial rolling, pushing the boundaries of mechanical minimization.
*   **RiftWalker Inspiration:** The emphasis on hyper-efficient hardware utilization inspired RiftWalker’s elimination of complex, heavy steering racks. Instead of dedicated steering hardware, RiftWalker relies entirely on `differential thrust` and the dual-purpose nature of our XPS foam wheels (acting as both ground clearance and marine pontoons).

<br>

---

## Research Gap & The RiftWalker Solution

While existing literature demonstrates the theoretical viability of multi-terrain robotics, the current generation of triphibious prototypes consistently suffers from three critical engineering flaws:

*   **High Mechanical Complexity:** Reliance on heavy steering racks, independent drive axles, and redundant marine thrusters.
*   **Terrain-Locking & Parasitic Mass:** When operating in one domain (e.g., flight), the hardware dedicated to the other two domains becomes dead-weight, severely degrading battery life and maneuverability.
*   **Bloated Avionics:** Dependence on off-the-shelf, single-domain flight controllers that lack the multi-threaded processing required for instantaneous shape-shifting and cross-domain stabilization.

<br>

### Our Approach: The RiftWalker Architecture
RiftWalker is engineered to bridge these gaps by delivering a highly scalable, maximum-efficiency architecture that completely eliminates parasitic drivetrain weight. We achieve this through three core pillars:

#### 1. Unified Mechatronic Mechanism
By deploying high-torque digital servos, the entire BLDC propulsion system is dynamically vectored. This allows RiftWalker to steer across land and water using pure differential thrust, aided by underslung closed-cell XPS foam wheels that provide mechanical clearance on land and precise buoyancy control on water.

#### 2. Custom Multi-Domain Avionics
Bypassing pre-existing, off-the-shelf software, RiftWalker is powered by a custom-engineered `ESP32-S3 PCB`. This hardware features strict power and sensor isolation to protect sensitive IMU and barometric data from high-current servo spikes.

#### 3. Real-Time Dual-Core Processing
Utilizing a custom FreeRTOS firmware written from scratch, RiftWalker dedicates one processing core exclusively to `environmental sensor fusion` (detecting the active domain) and the second core strictly to the `PID stabilization` and motor timing loops, ensuring seamless, interruption-free transitions across air, land, and water.

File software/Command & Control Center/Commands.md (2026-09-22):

# RIFTWALKER // Triphibious Command Deck

Source-locked command deck for the triphibious vehicle (air, land, water). Local simulation always works. Live ESP32 telemetry is shown only after the device answers the API contract below.

## Files

| Path | Role |
|---|---|
| `Index.html` | Canonical Command Deck. Open this in a browser, or let the desktop app load it. |
| `Application/index.html` | Exact copy of the canonical HTML, so the `Application` folder can run on its own. |
| `Application/app.py` | Native desktop window (PySide6 + Qt WebEngine) that hosts the same HTML. |
| `Application/requirements.txt` | Python packages for the desktop app. |
| `READMED.md` | Architecture notes, pin map, and hardware contract. |

## Run in a browser

Double-click `Index.html`, or from this folder:

```powershell
Start-Process ".\Index.html"
```

No CDN, build step, or internet connection is required for simulation.

Optional local server (useful if a browser blocks `file://` features):

```powershell
python -m http.server 8765
```

Then open `http://127.0.0.1:8765/Index.html.html`.

## Run the desktop app

Requires **Python 3.10+**.

```powershell
cd Application
python -m pip install -r requirements.txt
python app.py
```

Or from this folder:

```powershell
python -m pip install -r Application\requirements.txt
python Application\app.py
```

The window loads the same Command Deck HTML (System, Digital Twin, Hardware / PCB, Use Cases, Ground Control, Reference Gallery). Drag to orbit the model; mouse wheel zooms.

## What works without hardware

- Air / Land / Water modes and vector animation (120°/s)
- Vector changes **propeller direction only**; the model does not drop when you vector
- Environment pressure and Ground Control **UP / DOWN** move the vehicle up or down **inside the same view** (window size stays put)
- Throttle, vector, and environment-pressure controls
- Ground Control pad: UP, DOWN, FWD, BACK, LEFT, RIGHT, STOP
- Live local telemetry (mode, altitude, speed, pressure, battery, roll, pitch, current, power, per-servo angles)
- Interactive PCB map, mission cases, and the supplied reference gallery
- Ground-control pad, ESTOP, and command log in **local simulation** mode

## ESP32 hardware link

Ground Control uses:

- `GET /health`
- `GET /telemetry`
- `POST /command` with JSON

Until those endpoints succeed, the UI stays on **SIMULATION**. It never labels local variables as “ESP32 LIVE”.

Firmware must allow CORS if the page origin is not the ESP32 itself.

Example telemetry:

```json
{
  "ok": true,
  "mode": "air",
  "throttle": 42,
  "vector": 90,
  "altitude": 1.25,
  "pressure": 998.4,
  "speed": 18.2,
  "roll": -1.1,
  "pitch": 2.4,
  "battery": 91,
  "current": 18.6,
  "power": 275
}
```

## Safety

This is a visualization and operator-deck prototype, not a certified flight controller. Test motors with propellers removed or restrained, and keep a physical emergency-disarm path.

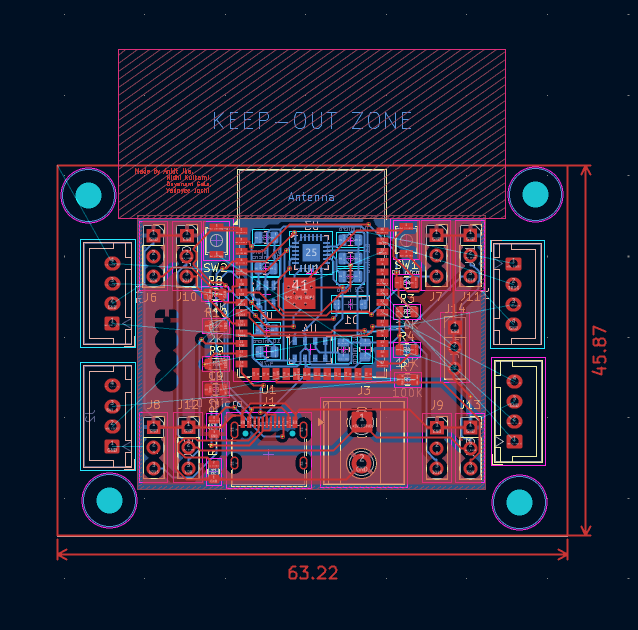
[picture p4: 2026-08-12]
hardware/PCB/PCB Dimensions.png

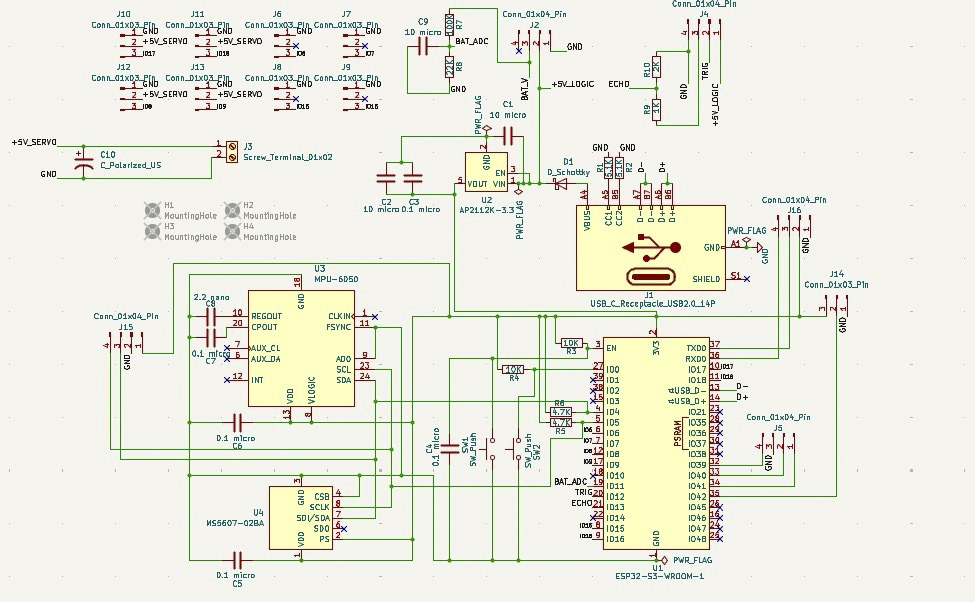
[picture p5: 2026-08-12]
images/circuit_diagram-2.jpg

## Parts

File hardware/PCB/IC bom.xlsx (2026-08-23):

Sr. No | Description | Components | Quantity | Price | Links
1 | Gyro+ Acc | MPU6050 IC SMD | 1 | 272.58 | https://zbotic.in/product/mpu-6050-qfn-24-3-axis-gyro-accelerometer-ic/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
2 | Voltage Regulator | AP2212K-3.3 IC SMD | 1 | 18 | https://robu.in/product/ap2128k-3-3trg1-diodes-incorporated-300ma-fixed-3-3v-positive-6v-sot-23-5-voltage-regulators-linear-low-drop-out-ldo-regulators-rohs/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
3 | C-PORT | USB C receptable-2.0 IC | 1 | 85.55 | https://www.lioncircuits.com/parts/USB4500-03-0-A
4 | Controller | ESP32-S3 IC SMD | 1 | 235 | https://www.flyrobo.in/esp32-s3-wi-fi-plus-bluetooth-5.0-2mb-32-bit-mcu-chip?tracking=ads
5 | Altimeter | MS5607-02BA IC SMD | 1 | 952.76 | https://in.element14.com/te-connectivity/ms560702ba03-50/sensor-barometric-0-01-1-2bar/dp/2362660
6 | 1x2 | Screw Terminal 1x2 | 1 | 15 | https://vishaworld.com/products/xy126-2-pin-screw-terminal-block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
7 | Push button | SMD button | 2 | 87.2 | https://in.element14.com/omron-electronic-components/b3u-1000p/tactile-switch-spst-no-0-05a-smd/dp/2500851
8 | 1000uF | Polarized capacitor THT | 1 | 18 | https://harishprojects.com/products/1000uf-63v-electrolytic-capacitor-for-power-supply-diy-projects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
9 | 1 x 3 | JST connector - male | 10 | 1.5 | https://www.flyrobo.in/3-pin-male-rmc-connector-2.54mm-pitch?tracking=ads
10 | 1 x 4 | JST connector - male | 5 | 1.71 | https://www.ktron.in/product/4-pin-jst-xh-male-connector-2-54mm-pitch/
11 | 4.7k | Resistor SMD | 2
12 | 1k | Resistor SMD | 1
13 | 2k | Resistor SMD | 1
14 | 5.1k | Resistor SMD | 2
15 | 10k | Resistor SMD | 2
16 | 100k | Resistor SMD | 1
17 | 22k | Resistor SMD | 1
18 | 10u | Capacitor SMD | 2
19 | 0.1u | Capacitor SMD | 5
20 | 2.2n | Capacitor SMD | 1

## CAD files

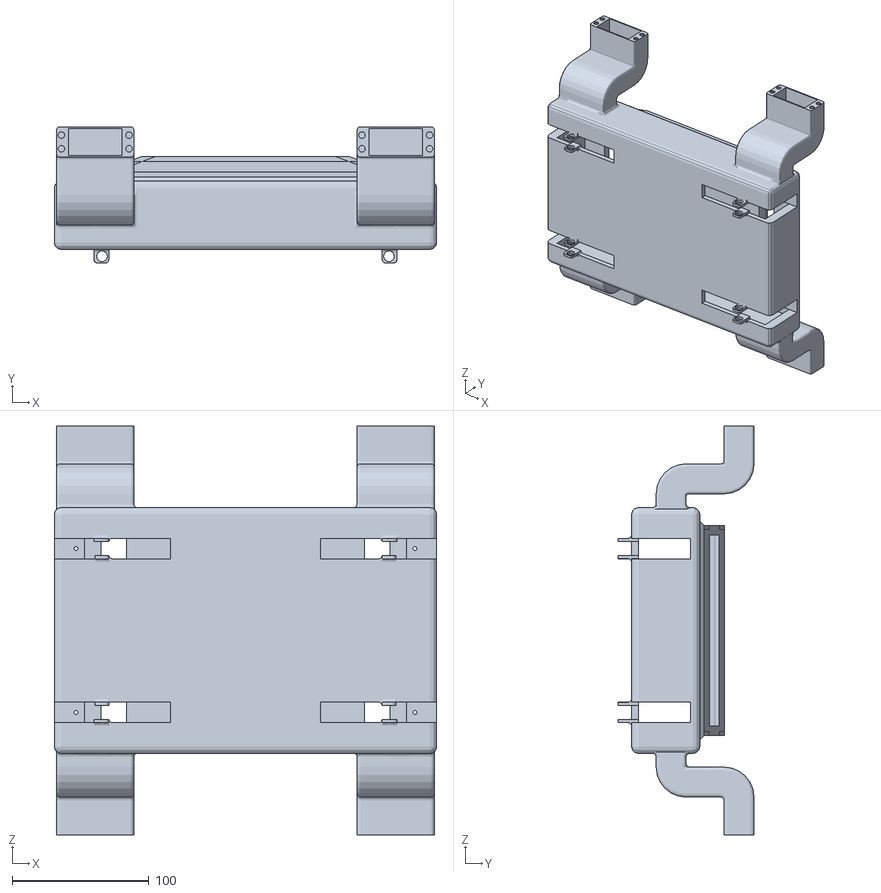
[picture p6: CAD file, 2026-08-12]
hardware/CAD/TEST ASSEMBLY 1.stl
280.0 x 99.7 x 299.4

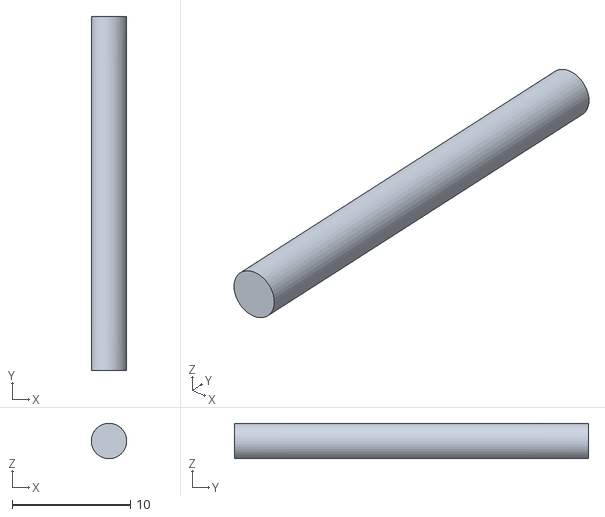
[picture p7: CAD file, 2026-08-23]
hardware/CAD/Connecting Rod.stl
3.00 x 30.0 x 3.00

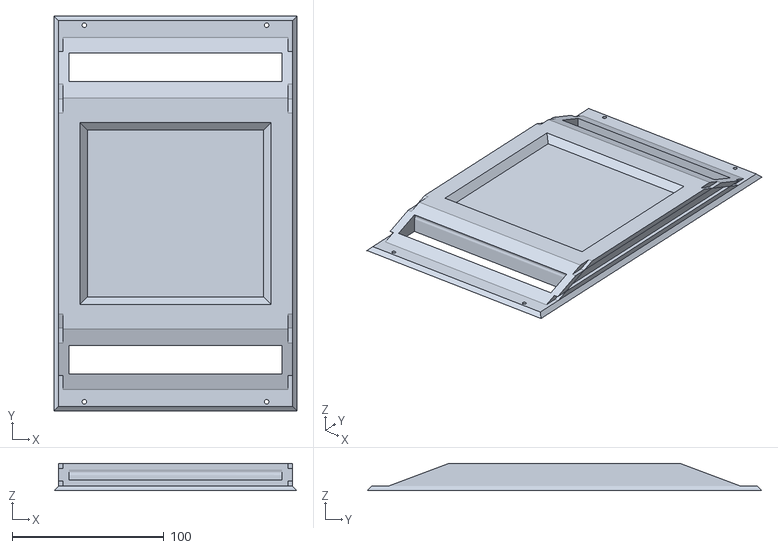
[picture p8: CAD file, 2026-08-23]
hardware/CAD/Top Cover.stl
160.0 x 260.0 x 18.0

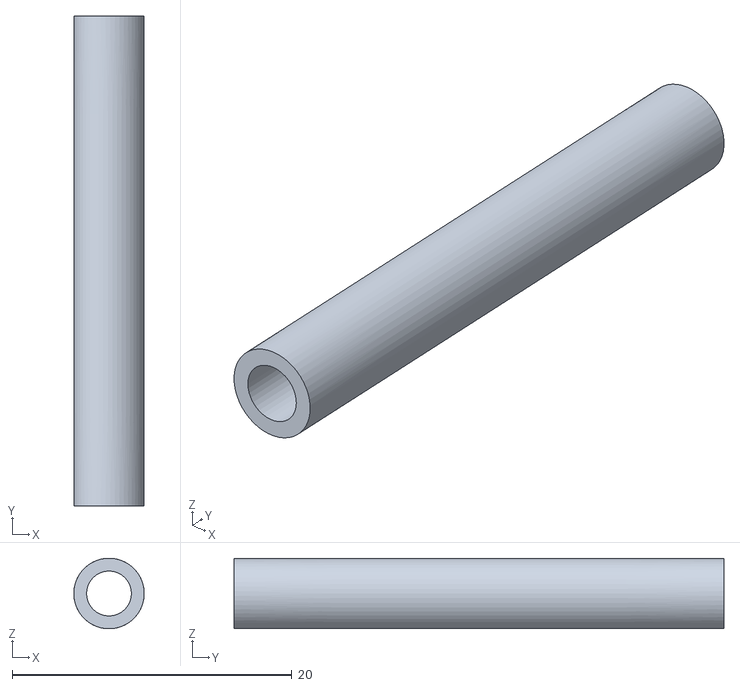
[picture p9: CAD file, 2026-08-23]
hardware/CAD/Pcb Spacer.stl
5.03 x 35.0 x 5.03

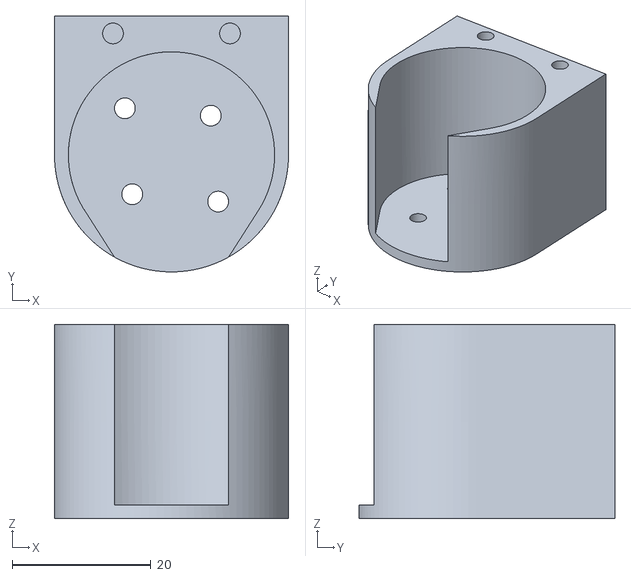
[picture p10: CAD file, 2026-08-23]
hardware/CAD/BLDC Holder.stl
33.7 x 36.8 x 28.0

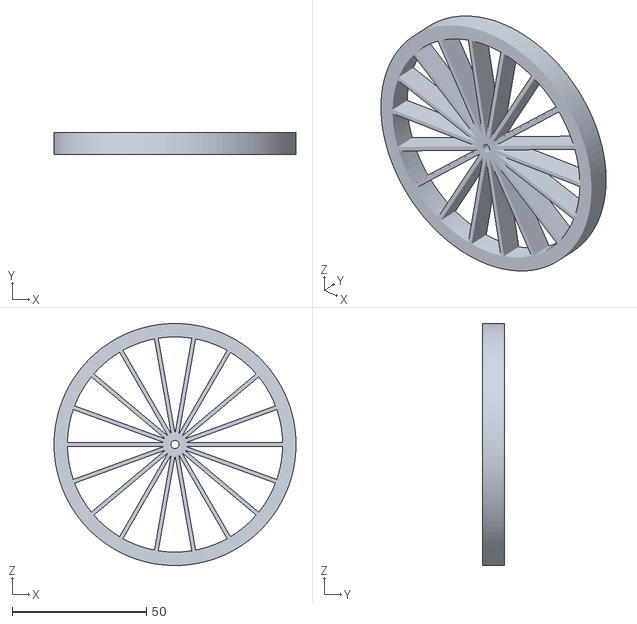
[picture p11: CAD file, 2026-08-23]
hardware/CAD/Tyres.stl
90.0 x 8.00 x 90.0

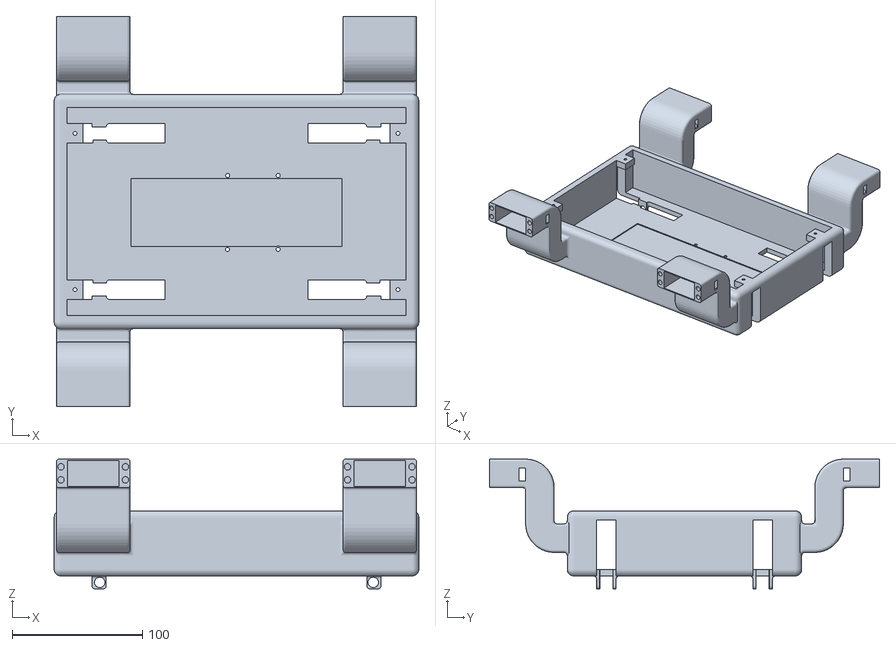
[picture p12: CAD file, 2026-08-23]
hardware/CAD/Body.stl
280.0 x 299.4 x 99.7

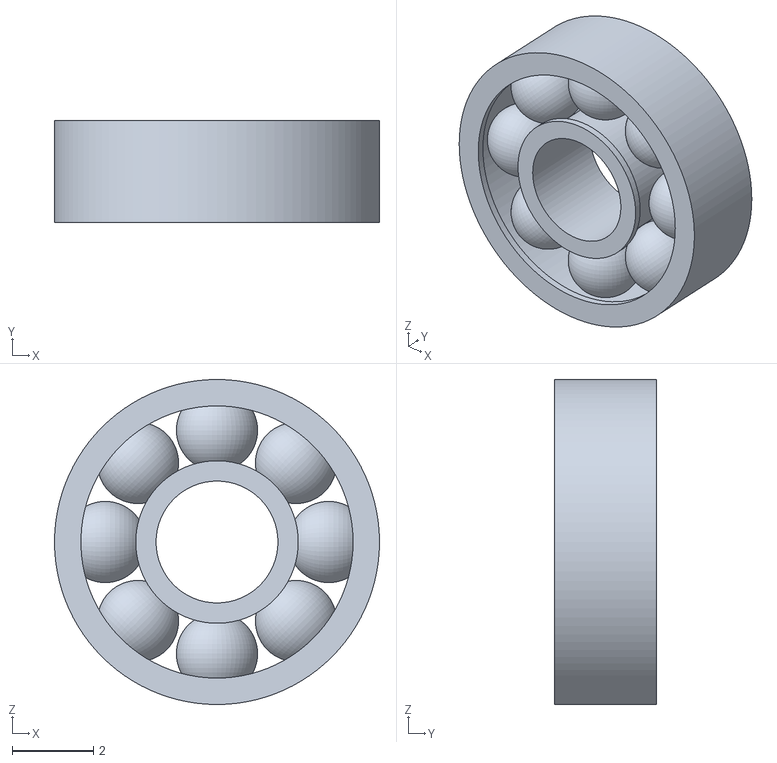
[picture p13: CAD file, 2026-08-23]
hardware/CAD/Bearing.stl
8.00 x 2.50 x 8.00

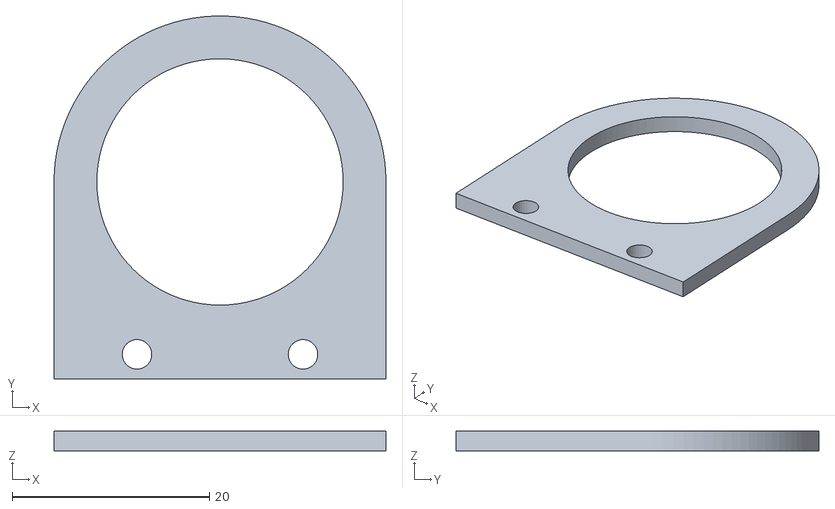
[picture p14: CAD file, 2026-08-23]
hardware/CAD/Holder Cover.stl
33.7 x 36.8 x 2.00

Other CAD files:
hardware/CAD/BLDC Holder.ipt
hardware/CAD/Bearing.ipt
hardware/CAD/Body.ipt
hardware/CAD/Connecting Rod.ipt
hardware/CAD/Final Body.iam
hardware/CAD/Holder Cover.ipt
hardware/CAD/Motor.ipt
hardware/CAD/Propeller.ipt
hardware/CAD/Servo.ipt
hardware/CAD/Top Cover.ipt
hardware/CAD/Tyres.ipt

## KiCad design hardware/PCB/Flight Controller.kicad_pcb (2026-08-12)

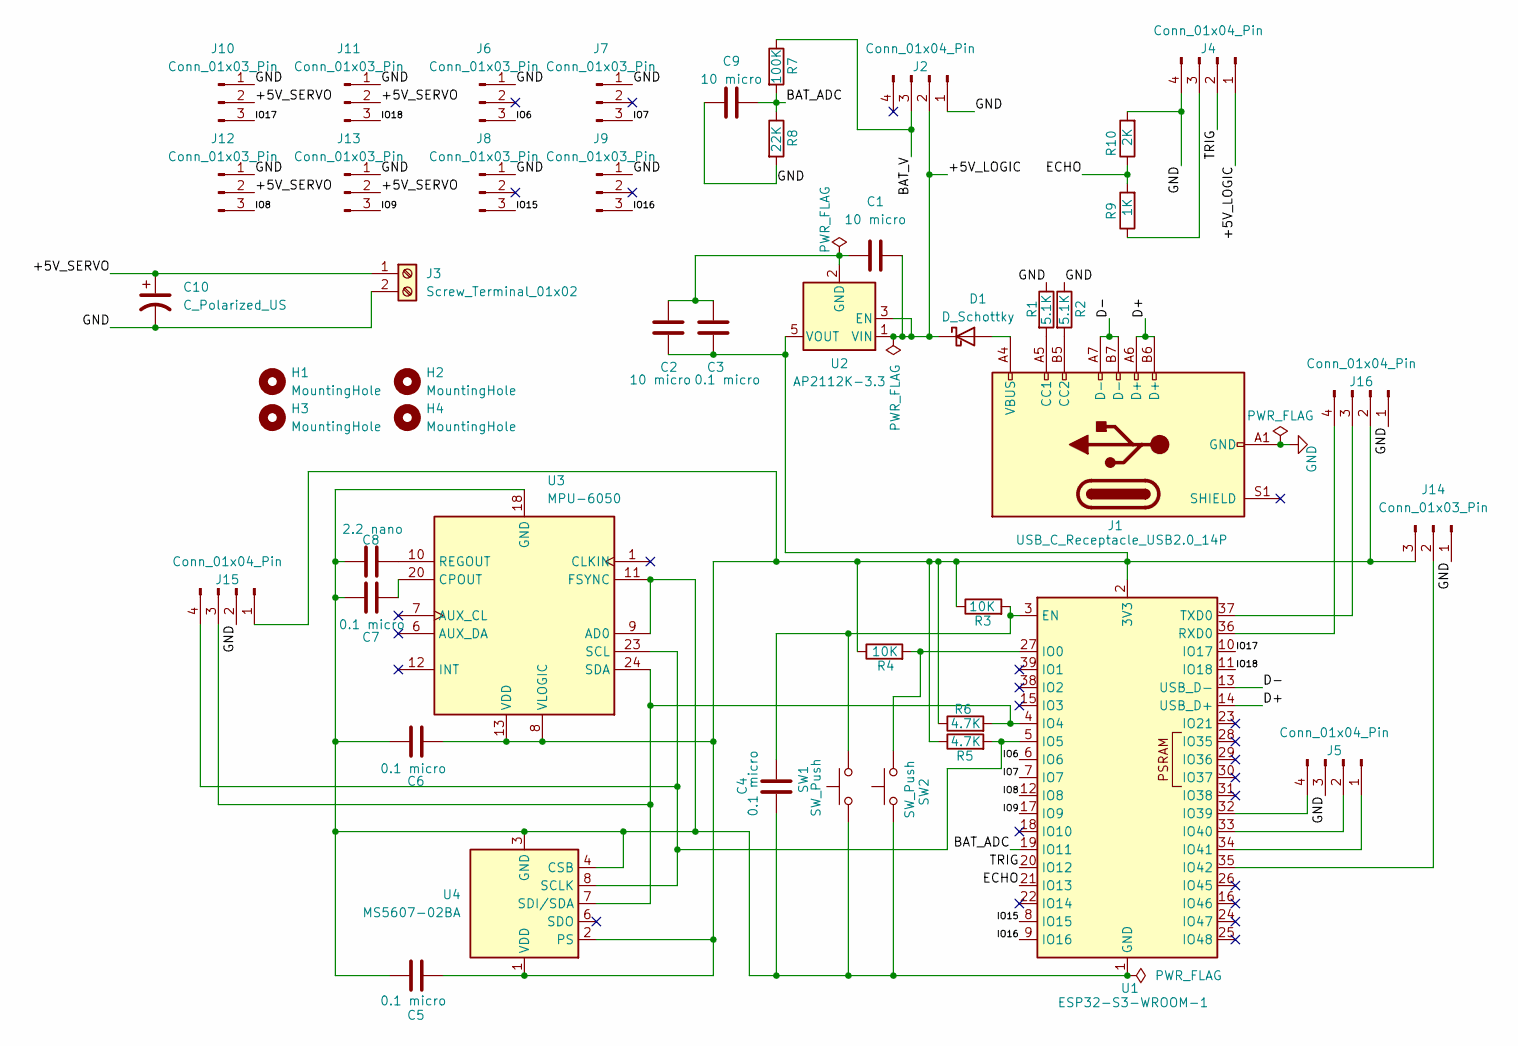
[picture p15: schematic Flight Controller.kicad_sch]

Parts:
C1, C2, C9: 10 micro; C_0805_2012Metric
C3, C4, C5, C6, C7: 0.1 micro; C_0805_2012Metric
C8: 2.2 nano; C_0805_2012Metric
C10: C_Polarized_US; CP_Radial_D10.0mm_P5.00mm
D1: D_Schottky; D_SOD-123
H1, H2, H3, H4: MountingHole; MountingHole_3.2mm_M3
J1: USB_C_Receptacle_USB2.0_14P; USB_C_Receptacle_HRO_TYPE-C-31-M-12
J2, J4, J5, J15, J16: Conn_01x04_Pin; JST_XH_B4B-XH-A_1x04_P2.50mm_Vertical
J3: Screw_Terminal_01x02; TerminalBlock_Phoenix_MKDS-1,5-2-5.08_1x02_P5.08mm_Horizont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
J6, J7, J8, J9, J10, J11, J12, J13: Conn_01x03_Pin; PinSocket_1x03_P2.54mm_Vertical
J14: Conn_01x03_Pin; PinHeader_1x03_P2.54mm_Vertical
R1, R2: 5.1K; R_0805_2012Metric
R3, R4: 10K; R_0805_2012Metric
R5, R6: 4.7K; R_0805_2012Metric
R7: 100K; R_0805_2012Metric
R8: 22K; R_0805_2012Metric
R9: 1K; R_0805_2012Metric
R10: 2K; R_0805_2012Metric
SW1, SW2: SW_Push; SW_SPST_B3U-1000P
U1: ESP32-S3-WROOM-1
U2: AP2112K-3.3; SOT-23-5
U3: MPU-6050; QFN-24-1EP_4x4mm_P0.5mm_EP2.15x2.15mm
U4: MS5607-02BA; LGA-8_3x5mm_P1.25mm

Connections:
/+5V_LOGIC: C1.2, D1.1 (K), J2.2, J4.1, U2.1 (VIN), U2.3 (EN)
/+5V_SERVO: C10.1, J3.1, J10.2, J11.2, J12.2, J13.2
/BAT_ADC: C9.2, R7.2, R8.1, U1.19 (IO11)
/BAT_V: J2.3, R7.1
/D+: J1.A6 (D+), J1.B6 (D+), U1.14 (USB_D+)
/D-: J1.A7 (D-), J1.B7 (D-), U1.13 (USB_D-)
/ECHO: R9.2, R10.1, U1.21 (IO13)
/IO6: J6.3, U1.6 (IO6)
/IO7: J7.3, U1.7 (IO7)
/IO8: J12.3, U1.12 (IO8)
/IO9: J13.3, U1.17 (IO9)
/IO15: J8.3, U1.8 (IO15)
/IO16: J9.3, U1.9 (IO16)
/IO17: J10.3, U1.10 (IO17)
/IO18: J11.3, U1.11 (IO18)
/TRIG: J4.2, U1.20 (IO12)
GND: C9.1, C10.2, J1.A1 (GND), J1.A12 (GND), J1.B1 (GND), J1.B12 (GND), J2.1, J3.2, J4.4, J5.3, J6.1, J7.1, J8.1, J9.1, J10.1, J11.1, J12.1, J13.1, J14.1, J15.2, J16.1, R1.1, R2.1, R8.2, R10.2
unnamed: D1.2 (A), J1.A4 (VBUS), J1.A9 (VBUS), J1.B4 (VBUS), J1.B9 (VBUS)
unnamed: J1.A5 (CC1), R1.2
unnamed: J1.B5 (CC2), R2.2
unnamed: J4.3, R9.1
unnamed: J5.1, U1.34 (IO41)
unnamed: J5.2, U1.33 (IO40)
unnamed: J5.4, U1.32 (IO39)
unnamed: J14.2, U1.35 (IO42)
unnamed: C2.2, C3.2, C5.2, C6.2, J14.3, J15.1, J16.2, R3.1, R4.1, R5.1, R6.1, U1.2 (3V3), U2.5 (VOUT), U3.8 (VLOGIC), U3.13 (VDD), U4.1 (VDD), U4.2 (PS)
unnamed: J15.3, R6.2, U1.4 (IO4), U3.24 (SDA), U4.7 (SDI/SDA)
unnamed: J15.4, R5.2, U1.5 (IO5), U3.23 (SCL), U4.8 (SCLK)
unnamed: J16.3, U1.37 (TXD0)
unnamed: J16.4, U1.36 (RXD0)
unnamed: C4.1, R3.2, SW1.2, U1.3 (EN)
unnamed: R4.2, SW2.2, U1.27 (IO0)
unnamed: C1.1, C2.1, C3.1, U2.2 (GND)
unnamed: C4.2, C5.1, C6.1, C7.1, C8.1, SW1.1, SW2.1, U1.1 (GND), U1.40 (GND), U1.41 (GND), U3.9 (AD0), U3.11 (FSYNC), U3.18 (GND), U4.3 (GND), U4.4 (CSB), U4.5 (CSB)
unnamed: C7.2, U3.20 (CPOUT)
unnamed: C8.2, U3.10 (REGOUT)

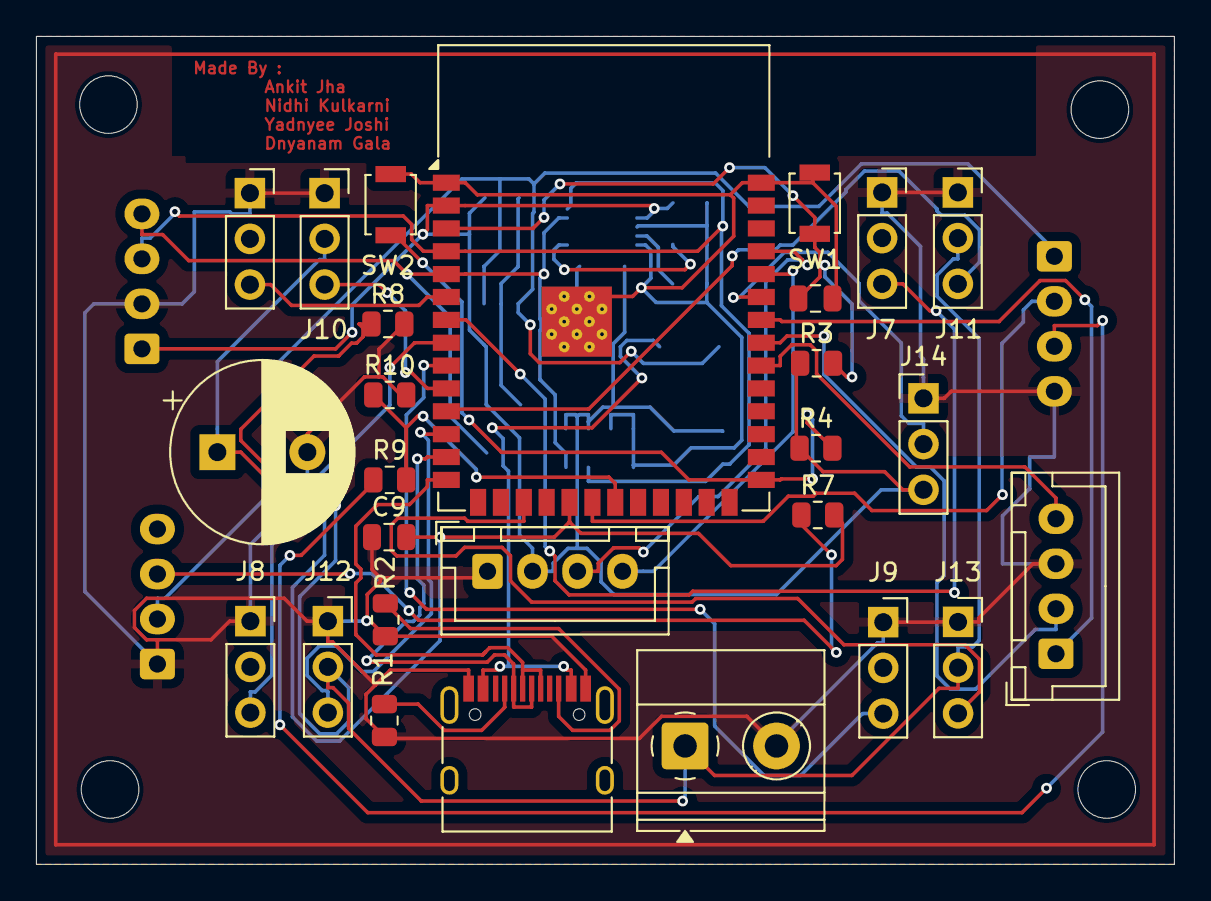
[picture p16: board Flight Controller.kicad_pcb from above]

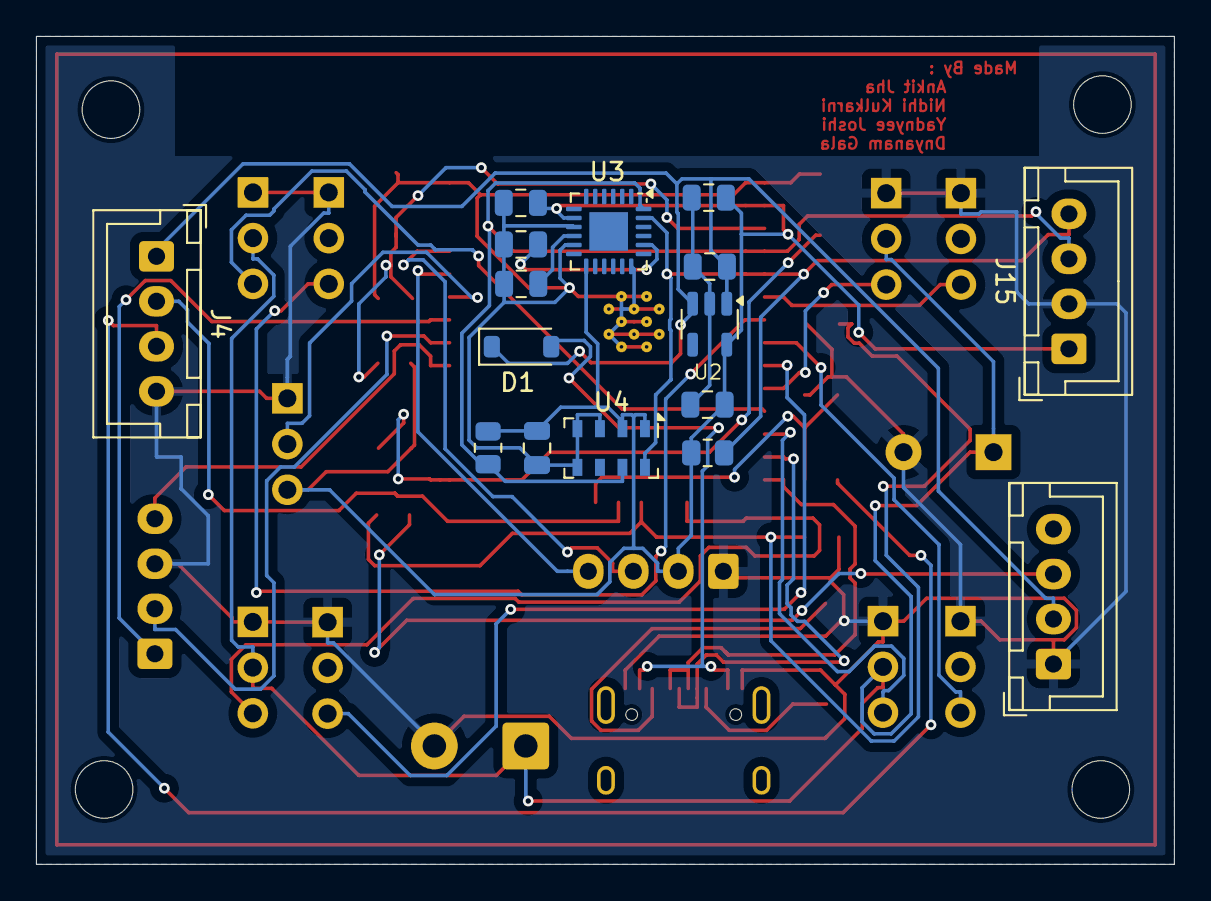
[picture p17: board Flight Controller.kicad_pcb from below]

Board: 2 copper layers, 63.2 x 46.0 mm, 47 parts (16 on the bottom side), 36 nets.

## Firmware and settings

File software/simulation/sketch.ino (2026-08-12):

#include <Wire.h>
#include <ESP32Servo.h>
#include <Adafruit_MPU6050.h>
#include <Adafruit_BMP085.h>
#include <Adafruit_SSD1306.h>

// ---------------- PIN MAPPING ----------------
#define TRIG 5
#define ECHO 35
#define POT_THR 34
#define BTN_FWD 26
#define BTN_BCK 25
#define BTN_LFT 17
#define BTN_RGT 15
#define BTN_WAT 16

#define STEP_FL 27
#define STEP_BL 14
#define STEP_FR 13
#define STEP_BR 12

#define DIR_L 32
#define DIR_R 33

#define S_FL 18
#define S_FR 19
#define S_BL 23
#define S_BR 4   // (change to 5 if hardware issue)

// ---------------- CONSTANTS ----------------
const int STEPS_PER_REV = 200;
const int MICROSTEPPING = 1;
const int TOTAL_STEPS = STEPS_PER_REV * MICROSTEPPING;

// ---------------- GLOBAL DATA ----------------
volatile float shared_dist = 0;
volatile float shared_pres = 1013.25;
volatile int shared_thr = 0;
volatile bool shared_water = false;
volatile bool shared_isFlying = false;

volatile float accX = 0, accY = 0;

String shared_status = "IDLE";
String stab_action = "LEVEL";

portMUX_TYPE mux = portMUX_INITIALIZER_UNLOCKED;

// ---------------- DEVICES ----------------
Adafruit_MPU6050 mpu;
Adafruit_BMP085 bmp;
Adafruit_SSD1306 display(128, 64, &Wire, -1);
Servo servos[4];

// ---------------- SETUP ----------------
void setup() {
  Wire.begin(21, 22);
  Wire.setClock(400000);

  pinMode(BTN_FWD, INPUT_PULLUP);
  pinMode(BTN_BCK, INPUT_PULLUP);
  pinMode(BTN_LFT, INPUT_PULLUP);
  pinMode(BTN_RGT, INPUT_PULLUP);
  pinMode(BTN_WAT, INPUT_PULLUP);

  pinMode(DIR_L, OUTPUT);
  pinMode(DIR_R, OUTPUT);

  pinMode(STEP_FL, OUTPUT);
  pinMode(STEP_FR, OUTPUT);
  pinMode(STEP_BL, OUTPUT);
  pinMode(STEP_BR, OUTPUT);

  pinMode(TRIG, OUTPUT);
  pinMode(ECHO, INPUT);

  display.begin(SSD1306_SWITCHCAPVCC, 0x3C);

  bmp.begin();
  mpu.begin();

  servos[0].attach(S_FL);
  servos[1].attach(S_FR);
  servos[2].attach(S_BL);
  servos[3].attach(S_BR);

  xTaskCreatePinnedToCore(motorTask, "MotorTask", 4096, NULL, 3, NULL, 1);
  xTaskCreatePinnedToCore(sensorTask, "SensorTask", 4096, NULL, 1, NULL, 0);
}

// ---------------- MOTOR TASK ----------------
void motorTask(void * pvParameters) {

  const float MAX_RPM = 1200;
  static uint32_t lastFL = 0, lastFR = 0, lastBL = 0, lastBR = 0;

  for (;;) {

    int thr;
    float localAccX, localAccY;
    bool isFlying, isWater;

    portENTER_CRITICAL(&mux);
    thr = shared_thr;
    localAccX = accX;
    localAccY = accY;
    isFlying = shared_isFlying;
    isWater = shared_water;
    portEXIT_CRITICAL(&mux);

    if (thr > 5) {

      float baseRPM = map(thr, 5, 100, 60, 600);
      float manualBoost = baseRPM * 0.8;
      float Kp = baseRPM*0.06;
      float rpmFL = baseRPM, rpmFR = baseRPM;
      float rpmBL = baseRPM, rpmBR = baseRPM;

      bool fwd = digitalRead(BTN_FWD) == LOW;
      bool bck = digitalRead(BTN_BCK) == LOW;
      bool lft = digitalRead(BTN_LFT) == LOW;
      bool rgt = digitalRead(BTN_RGT) == LOW;
      bool manual = (fwd || bck || lft || rgt);

      // -------- LAND/WATER --------
      if (isWater || !isFlying) {

        digitalWrite(DIR_L, HIGH);
        digitalWrite(DIR_R, HIGH);

        shared_status = isWater ? "SAILING" : "DRIVING";

        if (manual) {
          if (fwd) { pulse(STEP_BL); pulse(STEP_BR); }
          else if (bck) { pulse(STEP_FL); pulse(STEP_FR); }
          else if (lft) { pulse(STEP_FR); pulse(STEP_BR); }
          else if (rgt) { pulse(STEP_FL); pulse(STEP_BL); }
        }

        vTaskDelay(1);
        continue;
      }

      // -------- AIR MODE --------
      digitalWrite(DIR_L, HIGH);
      digitalWrite(DIR_R, LOW);

      if (manual) {
        shared_status = "MANUAL";
        // -------- MANUAL CONTROL (PUSH-PULL MIXING) --------
        if (fwd) {
          // Pitch forward → boost back, reduce front
          rpmBL += manualBoost;
          rpmBR += manualBoost;
          rpmFL -= manualBoost * 0.5;
          rpmFR -= manualBoost * 0.5;
        }
        if (bck) {
          // Pitch backward → boost front, reduce back
          rpmFL += manualBoost;
          rpmFR += manualBoost;
          rpmBL -= manualBoost * 0.5;
          rpmBR -= manualBoost * 0.5;
        }
        if (lft) {
          // Roll left → boost right, reduce left
          rpmFR += manualBoost;
          rpmBR += manualBoost;
          rpmFL -= manualBoost * 0.5;
          rpmBL -= manualBoost * 0.5;
        }
        if (rgt) {
          // Roll right → boost left, reduce right
          rpmFL += manualBoost;
          rpmBL += manualBoost;
          rpmFR -= manualBoost * 0.5;
          rpmBR -= manualBoost * 0.5;
        }

      } else {
        shared_status = "STABLE";

        float pitchErr = localAccX;
        float rollErr  = localAccY;

        if (abs(pitchErr) < 0.2) pitchErr = 0;
        if (abs(rollErr)  < 0.2) rollErr = 0;

        float pitchCorr = pitchErr * Kp;
        float rollCorr  = rollErr  * Kp;

        rpmFL += pitchCorr - rollCorr;
        rpmFR += pitchCorr + rollCorr;
        rpmBL -= pitchCorr - rollCorr;
        rpmBR -= pitchCorr + rollCorr;

        stab_action = (pitchErr == 0 && rollErr == 0) ? "LEVEL" : "CORR";
      }

      // -------- CLAMP --------
      auto clamp = [&](float &r) {
        if (r > MAX_RPM) r = MAX_RPM;
        if (r < 20) r = 20;
      };

      clamp(rpmFL); clamp(rpmFR);
      clamp(rpmBL); clamp(rpmBR);

      // -------- STEP CONTROL (REAL FIX) --------
      uint32_t now = micros();

      int dFL = 60000000 / (rpmFL * TOTAL_STEPS);
      int dFR = 60000000 / (rpmFR * TOTAL_STEPS);
      int dBL = 60000000 / (rpmBL * TOTAL_STEPS);
      int dBR = 60000000 / (rpmBR * TOTAL_STEPS);

      if (dFL < 150 ) dFL = 150 ;
      if (dFR < 150 ) dFR = 150 ;
      if (dBL < 150 ) dBL = 150 ;
      if (dBR < 150 ) dBR = 150 ;

      if (now - lastFL >= dFL) { pulse(STEP_FL); lastFL = now; }
      if (now - lastFR >= dFR) { pulse(STEP_FR); lastFR = now; }
      if (now - lastBL >= dBL) { pulse(STEP_BL); lastBL = now; }
      if (now - lastBR >= dBR) { pulse(STEP_BR); lastBR = now; }

    } else {
      shared_status = "OFF";
      vTaskDelay(10);
    }

    vTaskDelay(1);
  }
}

// ---------------- SENSOR TASK ----------------
void sensorTask(void * pvParameters) {

  float fAccX = 0, fAccY = 0;

  for (;;) {

    sensors_event_t a, g, temp;
    mpu.getEvent(&a, &g, &temp);

    fAccX = 0.8 * fAccX + 0.2 * a.acceleration.x;
    fAccY = 0.8 * fAccY + 0.2 * a.acceleration.y;

    digitalWrite(TRIG, LOW); delayMicroseconds(2);
    digitalWrite(TRIG, HIGH); delayMicroseconds(10);
    digitalWrite(TRIG, LOW);

    float dist = pulseIn(ECHO, HIGH, 25000) * 0.034 / 2;
    float pres = bmp.readPressure() / 100.0;
    int thr = map(analogRead(POT_THR), 0, 4095, 0, 100);
    bool water = (digitalRead(BTN_WAT) == LOW);

    bool flying = (pres < 1000.0 && dist > 100.0);

    portENTER_CRITICAL(&mux);
    accX = fAccX;
    accY = fAccY;
    shared_dist = dist;
    shared_pres = pres;
    shared_thr = thr;
    shared_water = water;
    shared_isFlying = flying;
    portEXIT_CRITICAL(&mux);

    // -------- SERVO --------
    float angle = (water || !flying) ? 0 : 90;

    for (int i = 0; i < 2; i++) servos[i].write(180 - angle);
    for (int i = 2; i < 4; i++) servos[i].write(angle);

    // -------- OLED --------
    display.clearDisplay();
    display.setTextColor(WHITE);
    display.setTextSize(1);

    display.setCursor(0, 0);
    display.print(water ? "MODE: WATER" : (flying ? "MODE: AIR" : "MODE: LAND"));

    display.setCursor(0, 10);
    display.print("STAB: ");
    display.println(stab_action);

    display.setCursor(0, 25);
    display.print("ALT: ");
    display.print(dist, 0);
    display.print("cm");

    display.setCursor(0, 35);
    display.print("P: ");
    display.print(pres, 0);

    display.setCursor(0, 45);
    display.print("STAT:");
    display.println(shared_status);

    display.setCursor(0, 55);
    display.print("THR:");
    display.print(thr);
    display.print("%");

    display.display();

    vTaskDelay(100);
  }
}

// ---------------- STEP PULSE ----------------
void pulse(int pin) {
  digitalWrite(pin, HIGH);
  delayMicroseconds(8);   // FIXED
  digitalWrite(pin, LOW);
}

void loop() {}

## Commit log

2026-08-12 Created CAD file for uploading model
2026-08-12 Created PCB file for uploading flight controller
2026-08-12 Upload RiftWalker CAD model
    [BLDC Holder.ipt, Bearing.ipt, Body.ipt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]
2026-08-12 Upload flight controller PCB design
    [Flight Controller.kicad_pcb, Flight Controller.kicad_sch]
2026-08-12 Add flowchart
2026-08-12 Add circuit diagram
2026-08-12 Updated System architecture, circuit diagram and flowchart
2026-08-12 Rename circuit diagram.jpeg to circuit_diagram.jpeg
2026-08-12 Document RiftWalker hardware architecture
    Added detailed hardware architecture documentation for the RiftWalker platform, including repository structure, mechanical design, custom avionics, and bill of materials.
2026-08-12 Expand RiftWalker Visual Repository documentation
    Added detailed explanations and references for system architecture, circuit diagrams, and software flowchart in the visual repository.
2026-08-12 Rename circuit diagram-2.jpg to circuit_diagram-2.jpg
2026-08-12 Updated circuit diagram-schematic pcb
2026-08-12 Updated circuit diagran
2026-08-23 Components for PCB
    [IC bom.xlsx]
2026-08-23 Updated PCB IC bom
2026-08-23 Finalized Design and Weekly Update #2
    [BLDC Holder.stl, Bearing.stl, Body.stl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]
2026-08-23 PCB IC bom
    [IC bom.xlsx]
2026-10-23 Add ESP-NOW Ground Transmitter functionality
    This file implements the ESP-NOW ground transmitter functionality for an ESP32-S3 board, including command handling and telemetry data processing.
